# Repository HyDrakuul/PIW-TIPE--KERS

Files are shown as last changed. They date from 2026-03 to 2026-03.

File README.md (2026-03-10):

# TIPE Flywheel Curve Analysis

**Project purpose:**
This personal project is centered around acquiring, processing, and comparing rotational speed curves from a flywheel setup (volant d'inertie). It combines embedded data acquisition (Arduino), serial communication (Python), and data analysis/plotting to evaluate mechanical energy and behavior. The model used for this project was entirely designed and manufactured by me (model available in 3D_model/, designed on Autodesk Fusion 360) and 3D printed with PLA filament.

---

## What’s in this repository

- **Arduino firmware**: `src/tiperoue/tiperoue.ino`
  - Measures rotations via inductive hand made sensors.
  - Sends `tours/s` and timestamp values over Serial.
  - Displays speed on an LCD.

- **Python acquisition scripts**:
  - `src/data_acquisition.py` – reads serial data, plots it, and optionally saves curves to CSV.
  - `src/TIPEcourbe.py` – lightweight acquisition + plotting helper.
  - `src/comparaisons.py` – compares stored curves and computes rotational energy.

- **Tests & hardware validation**:
  - `tests/test_graphical.py` – simple tkinter GUI that stops a long-running loop.
  - `tests/testbobine/testbobine.ino` – test sketch for validating hand-made sensor coils (bobines) via analog voltage readings.

- **Data & output folders**:
  - `raw_datas/` – stored measurement CSVs.
  - `bin_curves/` – generated plot exports (curve images).
  - `docs/` – documentation notes and supplementary materials.
  - `tipe-courbes/` – additional curve-related files.
  - `3D_model/` - 3D model in .step format (for maximum compatibility) and in .f3d (origin format, Fusion 360 compatible).

---

##  Skills developed

This project demonstrates and helps develop the following skills:

- Serial communication and realtime data acquisition (Arduino ↔ Python)
- Signal processing and data cleaning (conversion from raw serial strings)
- Data visualization (matplotlib plots of speed and energy curves)
- Reproducible data structuring with CSV exports
- Basic GUI interaction (user validation of measurement runs)
- Embedded firmware development (interrupts + timing in Arduino)
- 3D printing, 3D modelling, electromagnetic and mechanical physics.

---

##  Running the project

### 1) Upload the Arduino sketch

1. Open `src/tiperoue/tiperoue.ino` in the Arduino IDE.
2. Connect your Arduino and select the correct board/port.
3. Upload the sketch.

### 2) Acquire data with Python

1. Install Python dependencies: `pyserial`, `matplotlib`, `numpy`.
2. Run the acquisition script:

```bash
python src/data_acquisition.py
```
4. Run the experiment while running the two programs in parallel. 
3. A plot will appear at the end of the experiment. If you confirm the curve looks valid, it will be appended to a CSV.

---

##  How to reproduce / customize the data storage 

### Change where curves are stored

The storage locations are explicitly written in `src/data_acquisition.py` for the CSV file and experiment counter file. To make this reproducible:

- Modify the paths near the bottom of `src/data_acquisition.py` to target a relative folder (e.g., `./raw_datas/`) instead of an absolute desktop path.
- Example: replace `"/Users/…/TIPE/TIPE_experience2.csv"` with `"raw_datas/TIPE_experience2.csv"`.

### Load curves from files instead of hardcoded arrays

In `src/comparaisons.py`, curve data is currently embedded as multi-line strings (`rw_temps`, `rw_vitesse`, ...). To reproduce the analysis with your own curves:

1. Save data into a CSV (as above).
2. Replace the hardcoded strings with a loader such as `numpy.loadtxt` or `pandas.read_csv`.

---

##  Project structure (detailed)

This project is organized into a few main folders. The following breakdown
explains the purpose of each folder and the key files you’ll likely work with.

### Core source code (`src/`)

- `src/tiperoue/` – **Arduino firmware**
  - `tiperoue.ino` : main sketch that reads the sensor coils, computes rotational
    speed, prints it over Serial, and displays it on an LCD.

- `src/data_acquisition.py` – **serial data acquisition and CSV export**
  - Connects to the Arduino over a serial port.
  - Collects and cleans the raw velocity/timestamp stream.
  - Optionally saves each measurement run as a CSV.

- `src/TIPEcourbe.py` – **simple acquisition + plotting helper**
  - Smaller script for quickly plotting a single run without saving.

- `src/comparaisons.py` – **curve comparison + energy plotting**
  - Loads previously recorded curve data (currently embedded in the script)
  - Plots multiple flywheel curves together and computes rotational energy.

### Test & validation (`tests/`)

- `tests/test_graphical.py` – GUI loop-stop demo
  - Useful to verify that you can interrupt a long-running acquisition cleanly.

- `tests/testbobine/` – sensor coil validation
  - `testbobine.ino` : Arduino sketch that reads an analog pin (A0) and prints
    the voltage. This is intended to validate hand-made sensor coils / wiring.

### Data, exports and documentation

- `raw_datas/` – stored measurement CSV files (raw acquisitions).
- `bin_curves/` – exported plot images (curve screenshots, etc.).
- `docs/` – additional documentation notes, plan of the model, results presentations and bibliography.
- `tipe-courbes/` – additional curve assets (e.g., scripts or export formats).

### 3D model (`3D_model`)

- Includes two files who contain the 3D model of the modulable KERS system (same model just differents extensions). 

---

##  Notes

- For best reproducibility, keep all generated data inside `raw_datas/` and update the path constants in the Python scripts.
- If you want to run analyses on new data sets, update `src/comparaisons.py` to load from the relevant file(s) rather than using embedded arrays.

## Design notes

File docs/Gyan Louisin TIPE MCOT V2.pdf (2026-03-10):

39070 Gyan Louisin

### Modélisation et Étude d’un système mécanique de récupération d’énergie cinétique

Le 29 juillet 2009, lors du Grand Prix de Hongrie, le pilote Lewis Hamilton réalise une sortie exceptionnelle du peloton grâce à une utilisation maitrisée d’un tout nouveau système mécanique adopté pour la première fois dans l’histoire de la F1: le Système de Récupération d’Énergie Cinétique, ou SREC. L’introduction de ce système dans le sport automobile a ouvert de nouvelles perspectives en terme de stratégie de course. Il me paraissait donc intéressant d’étudier le fonctionnement de ce système et comment il pouvait impacter les performances d’un véhicule.

Positionnement thématique (ETAPE 1)

PHYSIQUE (Mécanique),INFORMATIQUE (Informatique pratique),SCIENCES INDUSTRIELLES (Conception de produit)
Mots-clés (ETAPE 1)
Mots-Clés (en français) | Mots-Clés (en anglais)
Système de Récupération d’Énergie Cinétique | Kinetic Energy Recovery System
Volant d’inertie | Flywheel
Moment d’inertie | Moment of Inertia
Modélisation 3D | 3D Modeling
Informatique Pratique | Practical Computing

Bibliographie commentée

Introduit dans la compétition de Formule 1 depuis 2009 [1], le SREC est un système basé sur la conversion énergétique. En effet, une course est une succession d'accélération et de décélérations et l’énergie cinétique fournie par le moteur, convertie en chaleur lors des phases de décélération, est perdue. L’idée du SREC est donc de stocker cette énergie cinétique avant qu’elle ne soit dissipée sous forme de chaleur en la convertissant en un autre type d’énergie (énergie électrique, de rotation...) pour ensuite être réutilisée ultérieurement, fournissant un gain de puissance, certes temporaire, mais non négligeable dans une course.

Ainsi, il existe principalement quatre types de SREC [2] : électrique, mécanique, hydraulique et hydroélectrique. Chacun de ces systèmes repose sur une méthode différente de stockage de l’énergie cinétique fournie par le moteur.

J’ai alors cherché à comprendre comment de tels systèmes pouvaient être dimensionnés afin d’être véritablement efficaces. Une étude approfondie de chacun des systèmes était alors nécessaire. J’ai exclu de mon étude les SREC hydraulique et hydroélectrique, de par leur complexité trop importante en vue d’une modélisation ultérieure.

Avant comparaison, il est nécessaire de préciser le fonctionnement de ces systèmes. Ainsi, les SREC électrique utilisent soit des batteries chimiques (Li-ions), soit des supercondensateurs pour le stockage de l’énergie électrique [2]. Les SREC mécanique utilisent des volants d’inertie, masses tournantes qui, comme leur nom l’indique, permettent le stockage par inertie d’une énergie cinétique de rotation, donnée par
avec J le moment d’inertie du volant en | , ω sa vitesse de rotation en | [4].

Après une première lecture des études comparatives réalisées en [2] et [3], on a pu exclure les SREC électrique utilisant des batteries, car malgré leurs avantages en termes de coût et de capacité de stockage, elles possèdent une densité de puissance très faible comparée au deux autres ([3]: « Tableau V.2 »; environ 300 W/kg contre plusieurs kW/kg), traduisant sa difficulté à transmettre une puissance importante au véhicule, ce qui oblige l’utilisation de batteries très onéreuses. Cela nous permet alors de nous concentrer sur les SREC mécanique et à supercondensateurs.

E = 1
2 ⋅ J ⋅ ω² | kg . m² | m .s⁻¹

39070 Gyan Louisin
Ensuite, [2] nous présente le SREC mécanique comme étant le plus intéressant selon des critères comme le coût et le rendement global. Cependant, il est aussi expliqué que cette étude a été faites à une époque où l’utilisation des supercondensateurs dans les SREC n’était pas industrielle et encore trop onéreuse.

SREC électriques mis de coté, j’ai étudié plus en profondeur les SREC mécanique. Ainsi, ces systèmes sont composés d’un couplage moteur-volant et d’un couplage volant-roue [1], mais l’aspect le plus important pour un SREC réside dans le dimensionnement du volant [4].

L’étude de [4] a permis de mettre en évidence l’influence de la forme du volant (cylindre plein, creux, « iso-contraintes »…) sur l’efficacité du système. En effet, cela provient directement de l’expression du moment
d’inertie, prenant en compte la répartition de la masse dans le volant: | avec mj une masse

individuelle du volant en kg et rj la position radiale de la masse mj en m. Dans cette optique, la masse du volant doit être relativement élevée et répartie le plus possibles sur sa périphérie afin de maximiser l’énergie stockée.

Problématique retenue

Comment réutiliser l’énergie cinétique emmagasinée par un SREC mécanique afin d’augmenter les performances d’un véhicule lors d’une course ?

Objectifs du TIPE

-Modéliser un SREC modulable, permettant d’effectuer diverses expériences pouvant mettre en évidence l’importance d’un tel système lors d’une course automobile.

-Réaliser la mesure de la vitesse de rotation de différents types de volants au cours du temps, permettant de mettre en relief l’importance de la masse et de sa répartition sur les performances du système.

-Montrer comment il est possible de transmettre l’énergie stockée du volant à la roue en modélisant un système de transmission roue-volant (embrayage).

-Mesurer le rendement du système ainsi fabriqué et mettre en lumière ses défauts par rapport à un système réel.

Références Bibliographiques (Étape 1)

[1] Alberto Boretti, Kinetic Energy Recovery System for Racing Cars, édité par SAE International, ISBN-13: 9780768079944
[2]Radhika Kapoor, C. Mallika Parveen, Member, IAENG, Proceedings of the World Congress on Engineering 2013 Vol III, Comparative Study on Various KERS,July 3 - 5, 2013, London, U.K.
[3]Khaled Itani. Récupération d’énergie pour système intégré moteur roue, application au véhicule électrique. Energie électrique. Université Paris Saclay (COmUE), 2017. Français. NNT: 2017SACLN025 . tel-01558984
[4]FAURE, F. Magnetic suspension for flywheel; Suspension magnetique pour volant d'inertie. 2003.TRN: FR0504123
[5]John Nussey, Arduino Pour les Nuls, 3e édition, édité par Pour Les Nuls, ISBN-13: 9782412077351

J = (

∑
j

### m jrj

2)

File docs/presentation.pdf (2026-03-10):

# Modélisation et

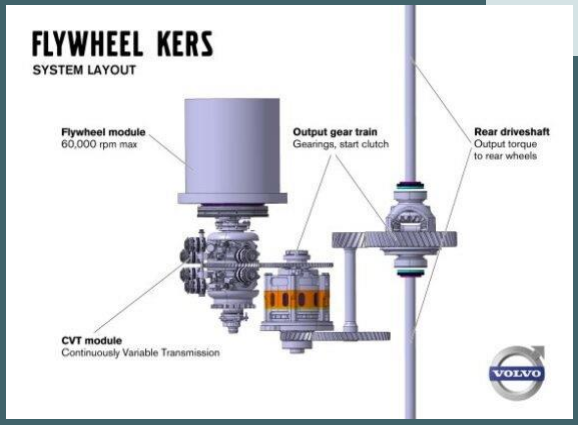
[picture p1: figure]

# Étude d’un système mécanique de récupération d’énergie

cinétique.

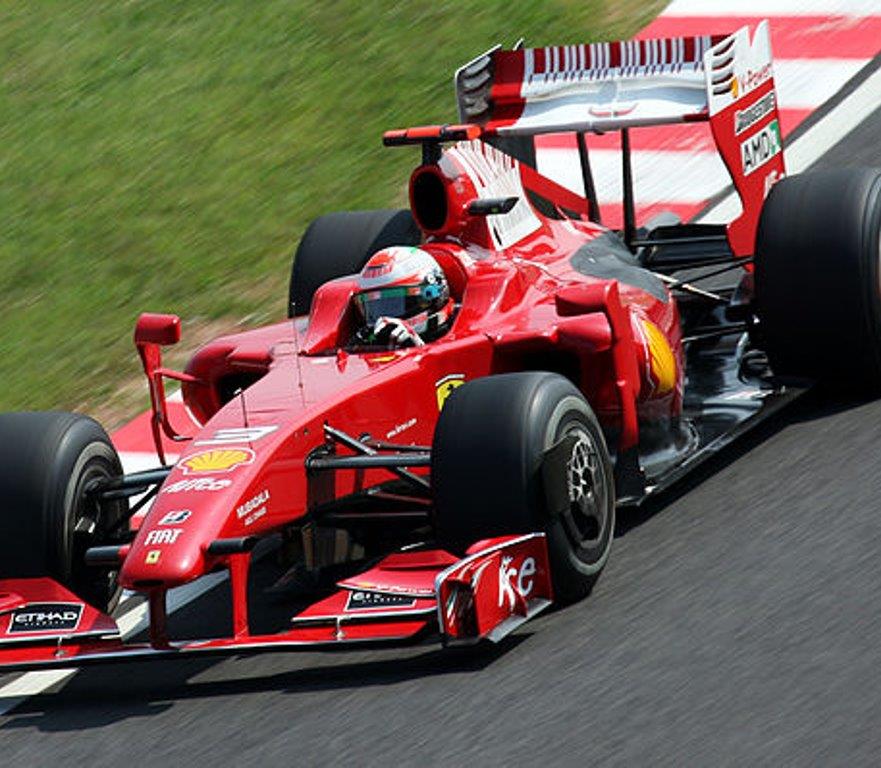
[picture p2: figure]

N°39070 Gyan Louisin

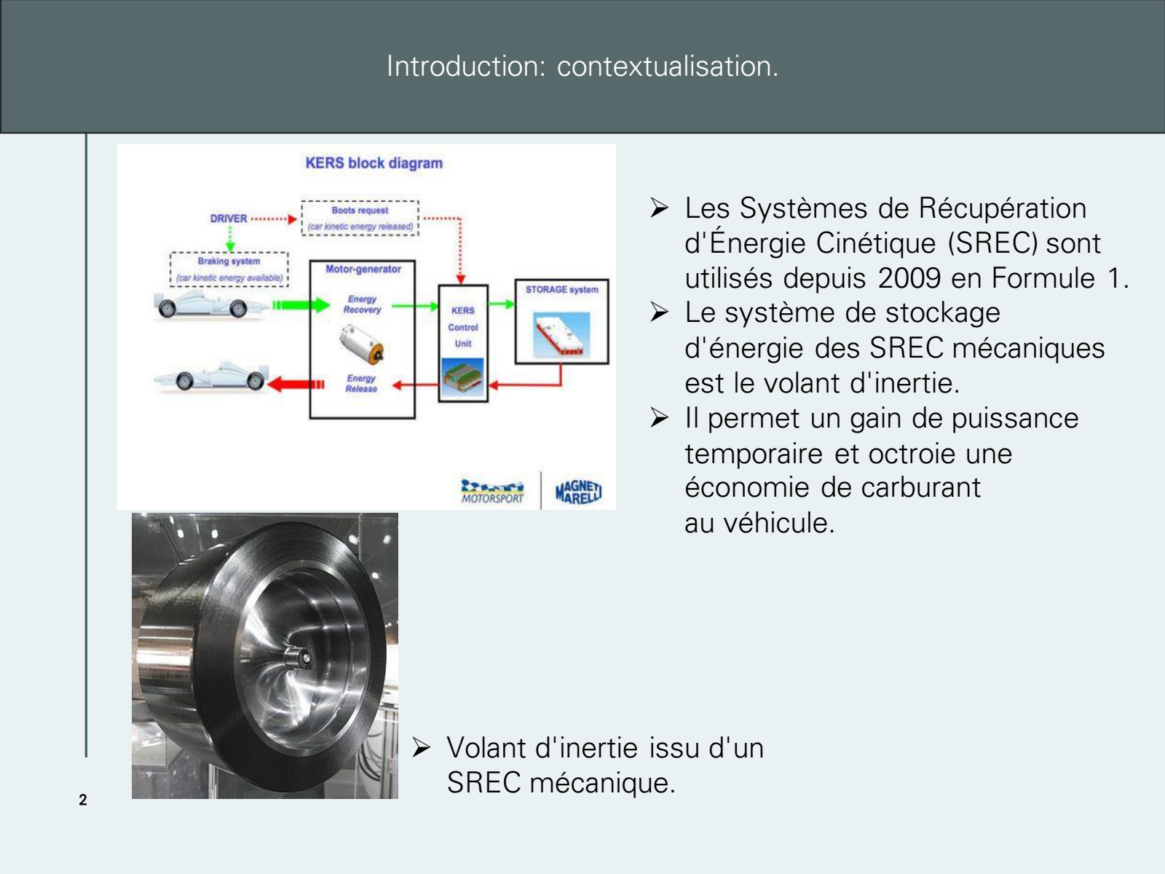
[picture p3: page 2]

2

Introduction: contextualisation.

- Volant d'inertie issu d'un SREC mécanique.
- Les Systèmes de Récupération d'Énergie Cinétique (SREC) sont utilisés depuis 2009 en Formule 1.
- Le système de stockage
d'énergie des SREC mécaniques est le volant d'inertie.
- Il permet un gain de puissance temporaire et octroie une
économie de carburant
au véhicule.

ΓΔ

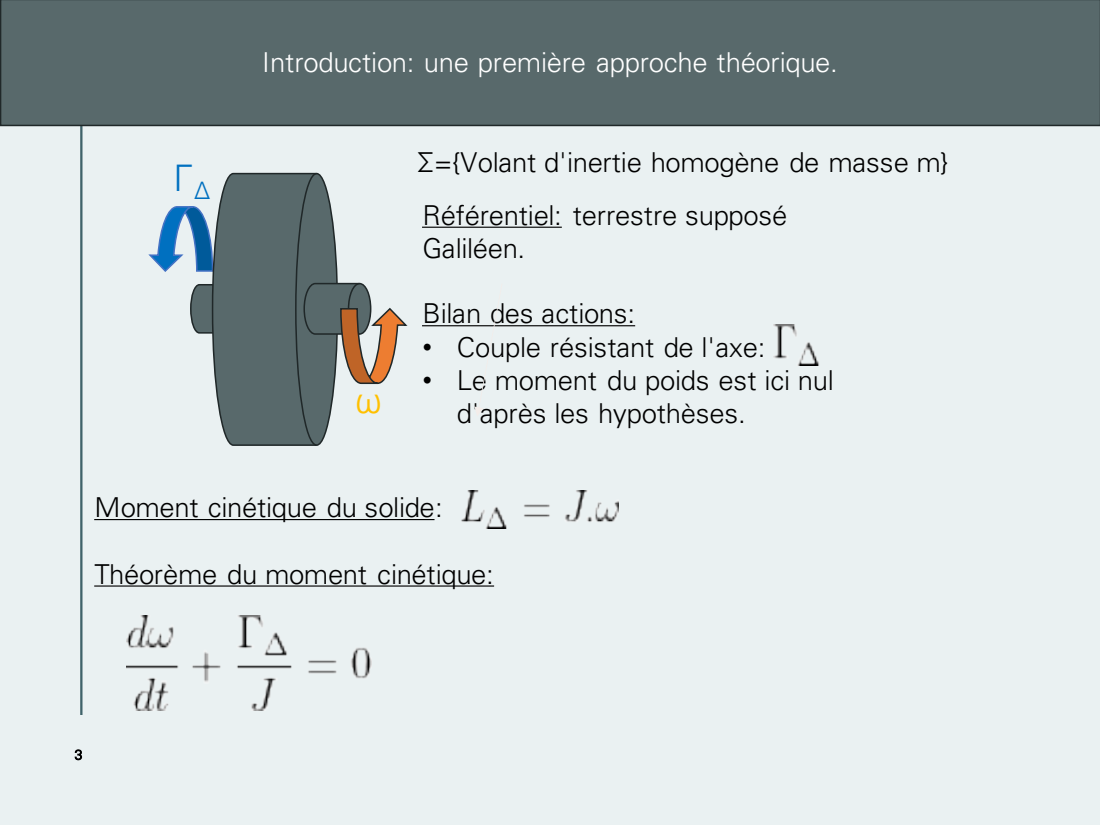
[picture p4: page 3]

Introduction: une première approche théorique.

Σ={Volant d'inertie homogène de masse m}

Référentiel: terrestre supposé
Galiléen.

Bilan des actions:
• Couple résistant de l'axe:
• Le moment du poids est ici nul

d'après les hypothèses.

Moment cinétique du solide:

Théorème du moment cinétique:

4

Introduction: une première approche théorique.

Une première expression de la vitesse du volant :

L'expression de l'énergie cinétique de rotation stockée:

L'expression du moment d'inertie du volant:

L'énergie stockée par le volant dépend de son moment d'inertie et donc de sa géométrie.

Comment réutiliser l’énergie cinétique emmagasinée par un SREC mécanique afin d’augmenter les performances d’un véhicule lors d’une course ?

5

Plan de la Présentation.

I. Modélisation: la construction du modèle réduit.

II. Expériences et résultats:

A. Expérience n°1: à la recherche d'un volant d'inertie optimal.
B. Expérience n°2: analyse des performances du système optimisé.

III. Bilan et discussion des limites du problème.

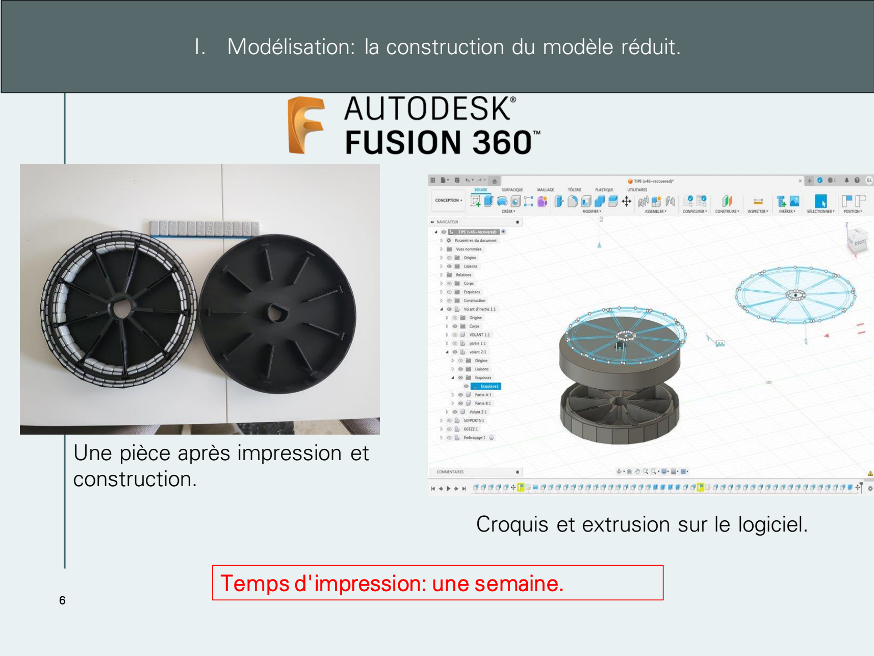
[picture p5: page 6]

6

I. Modélisation: la construction du modèle réduit.

Croquis et extrusion sur le logiciel.

Une pièce après impression et construction.

Temps d'impression: une semaine.

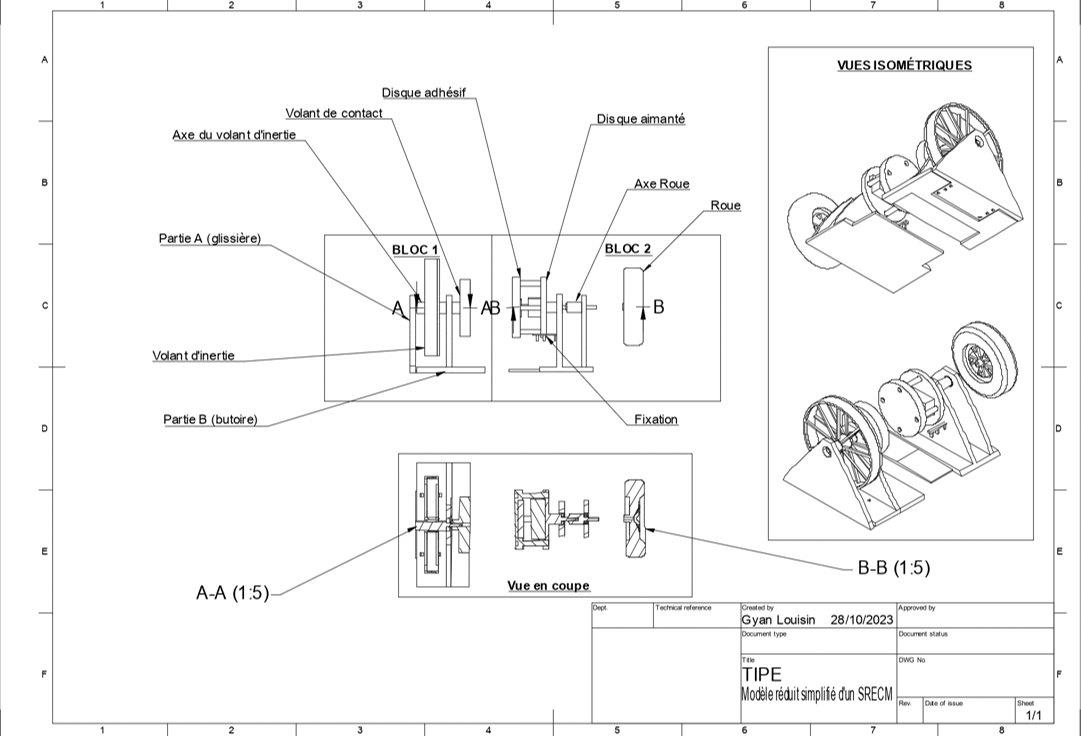
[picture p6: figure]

7

I. Modélisation: la construction du modèle réduit.

L'impression du modèle 3D.

8

I. Modélisation: la construction du modèle réduit.
- Objectif du modèle: simuler le transfert d'énergie du volant en décélération vers la roue.

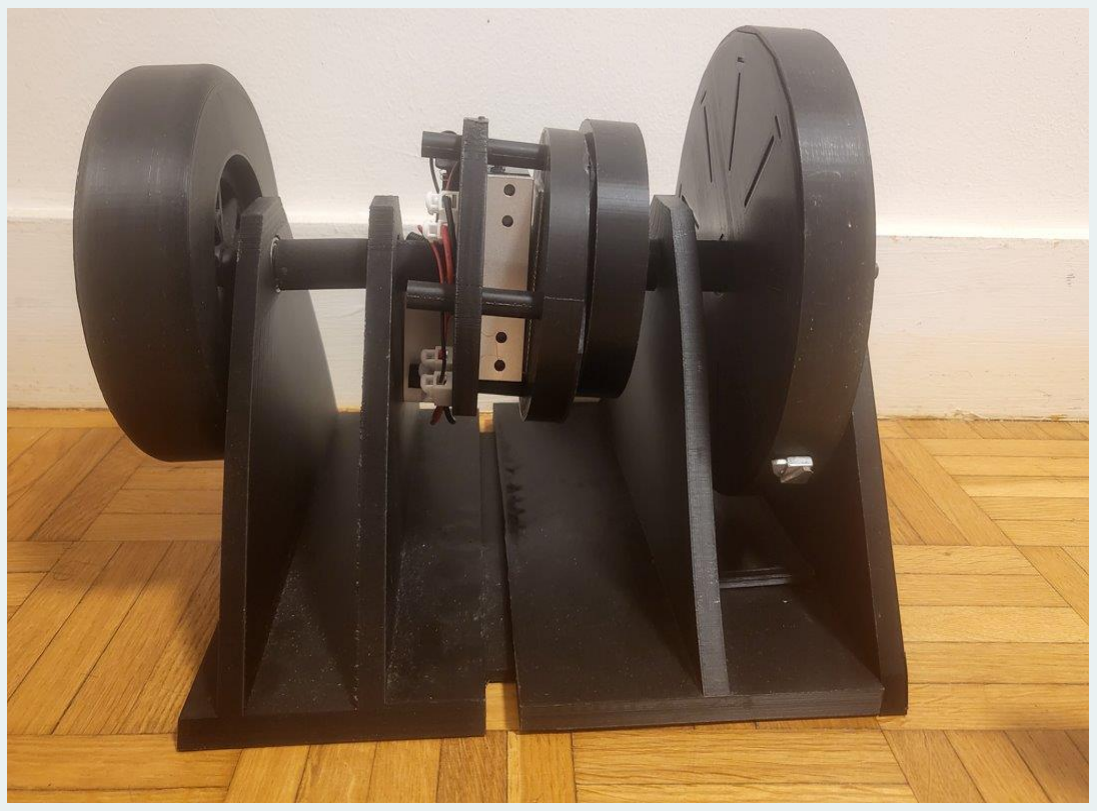
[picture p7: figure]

Comment obtenir la vitesse de rotation des différentes pièces ?

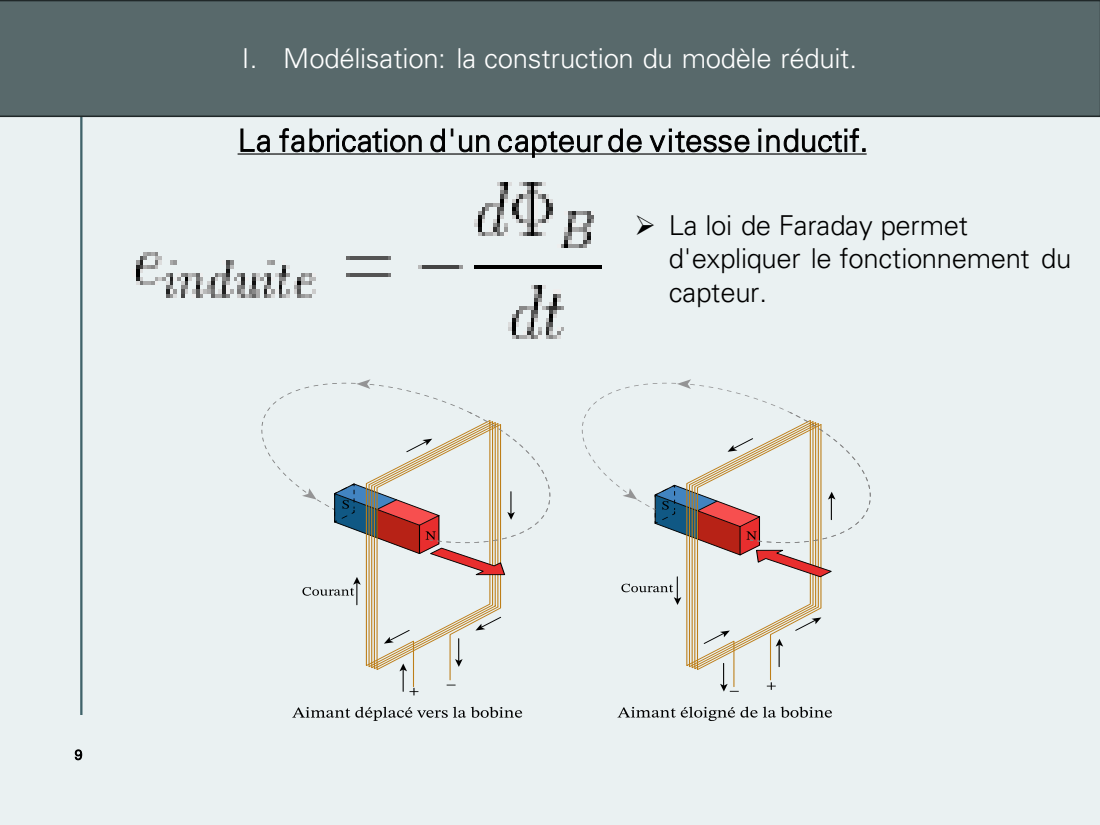
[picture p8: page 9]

I. Modélisation: la construction du modèle réduit.

La fabrication d'un capteur de vitesse inductif.

➢ La loi de Faraday permet
d'expliquer le fonctionnement du
capteur.

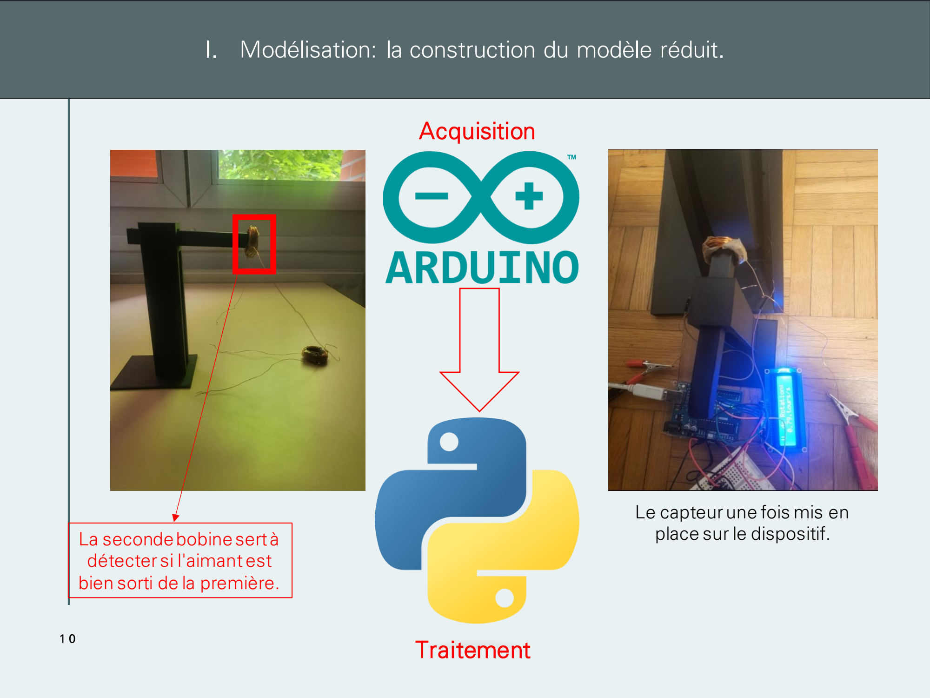
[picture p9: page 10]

10

I. Modélisation: la construction du modèle réduit.

La seconde bobine sert à
détecter si l'aimant est
bien sorti de la première.

Acquisition

Traitement

Le capteur une fois mis en place sur le dispositif.

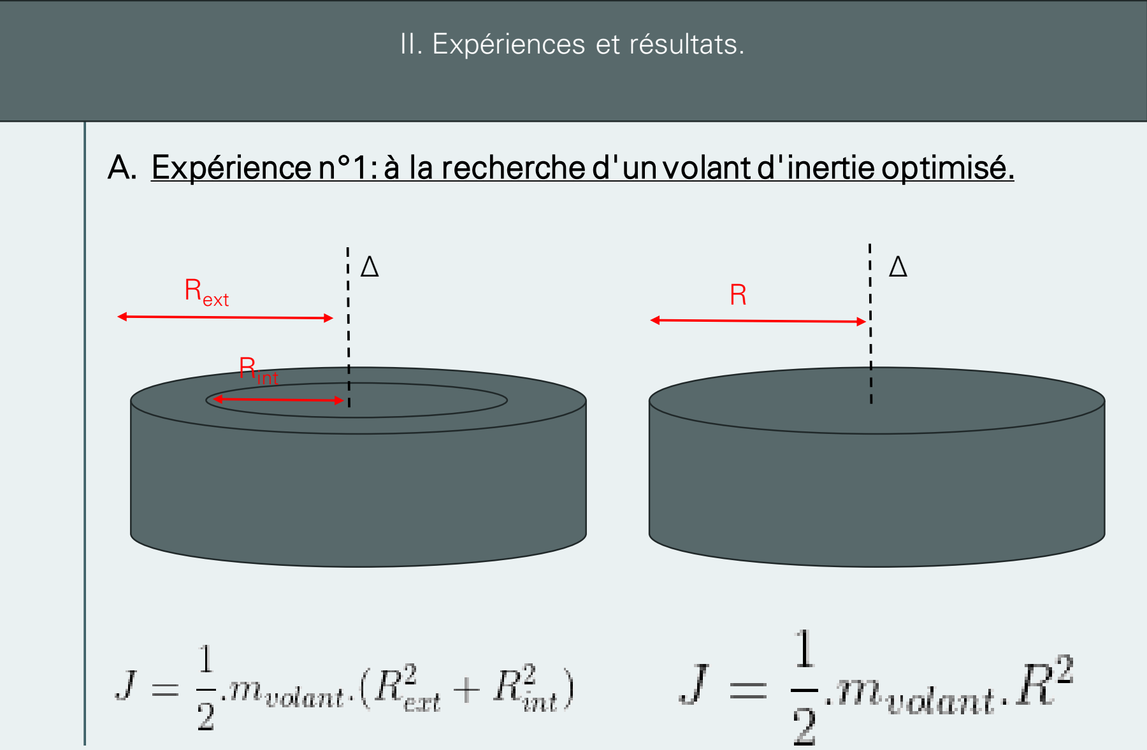
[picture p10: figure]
II. Expériences et résultats.; Rext; Rint

11

A. Expérience n°1: à la recherche d'un volant d'inertie optimisé.

12

Le montage utilisé.

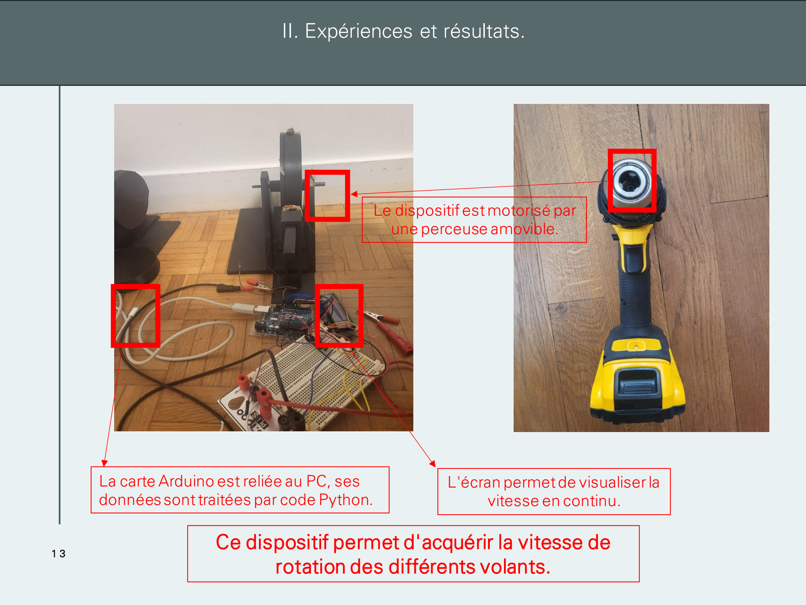
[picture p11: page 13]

13

L'écran permet de visualiser la vitesse en continu.

Le dispositif est motorisé par une perceuse amovible.

La carte Arduino est reliée au PC, ses données sont traitées par code Python.

Ce dispositif permet d'acquérir la vitesse de rotation des différents volants.

| Volant 1 | Volant 2 | Volant 3 | Volant4
Rayon(s) (cm) | Rint= 7.90 Rext= 9.20 | 9.20 | 6.50 | 9.20
Masse (kg) | 1.5 | 2 | 1.1 | 0.5
Répartition de la masse | Sur les bords extérie urs | Uniforme | Autour de l'axe/Uniforme | Vide
Moment d'inertie (kg.m² ) | (6.6±0.1)*10⁻² | (8.5±0.1) *10⁻³ | (2.32±0.04)*10⁻³ | (2.53±0.03)*10⁻³

14

Tableau présentant les caractéristiques des volants étudiés.

- Incertitude type sur le rayon: 0.06 cm

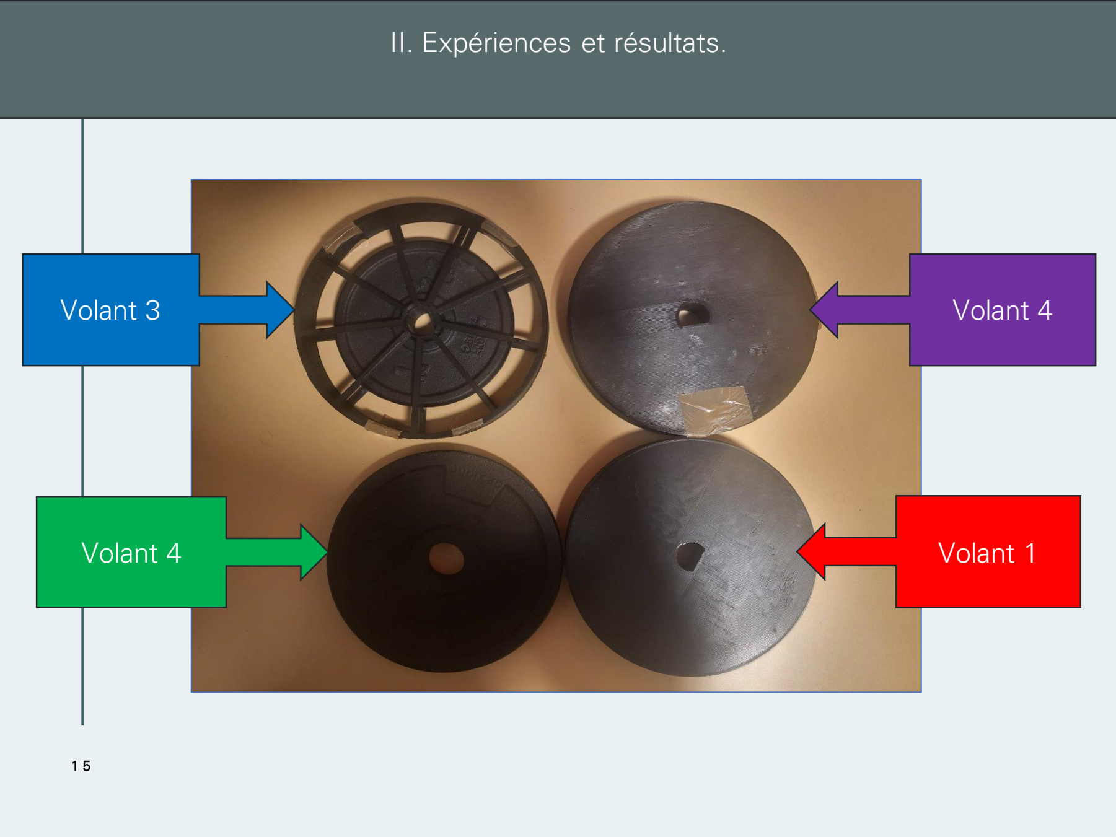
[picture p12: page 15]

15

Volant 1

Volant 3 | Volant 4

Volant 4

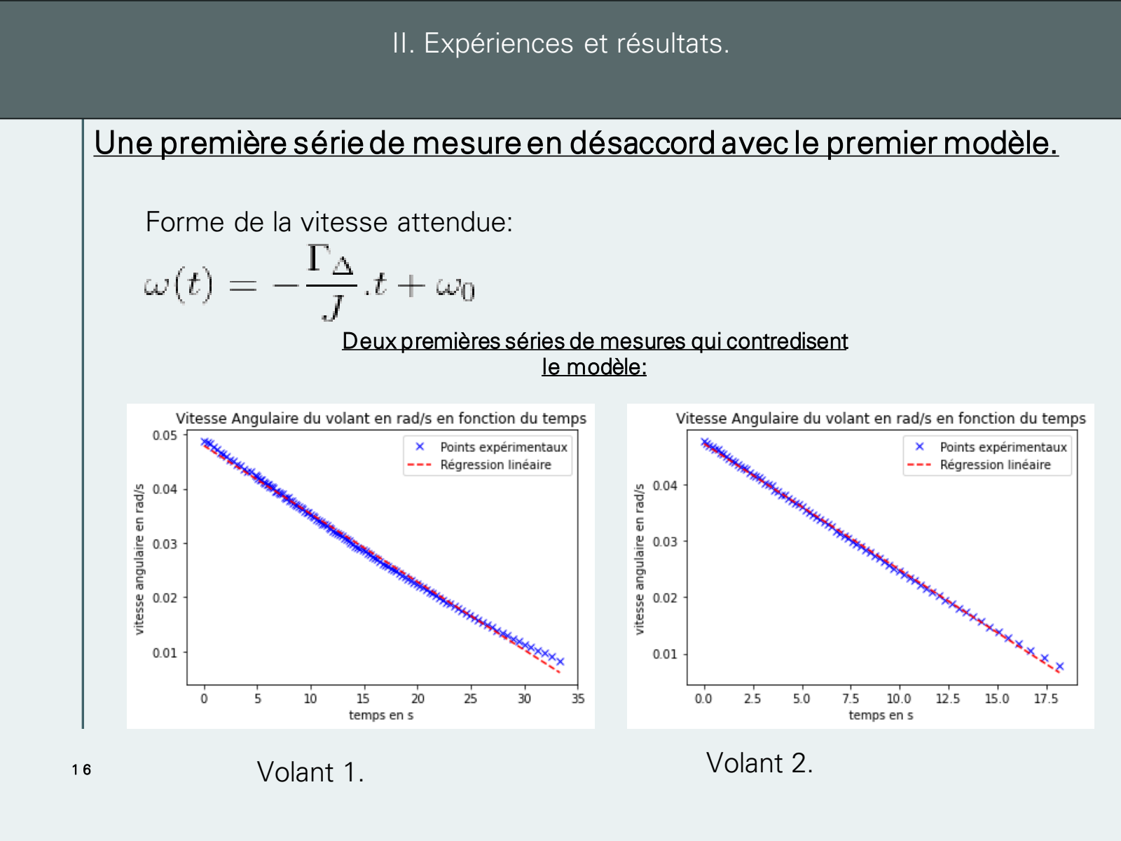
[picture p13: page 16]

16

Une première série de mesure en désaccord avec le premier modèle.

Forme de la vitesse attendue:

Deux premières séries de mesures qui contredisent le modèle:

Volant 1. | Volant 2.

17

Courbe présentant la phase de freinage (gain de vitesse du volant) et la phase de décélération, qui semble présenter une tendance non-linéaire.

18

Corrections apportées pour observer plus de points:
- Repositionnement du capteur.
- Minimisation des frottements parasites au niveau des roulements.
- Limitation des ballotements du volant.

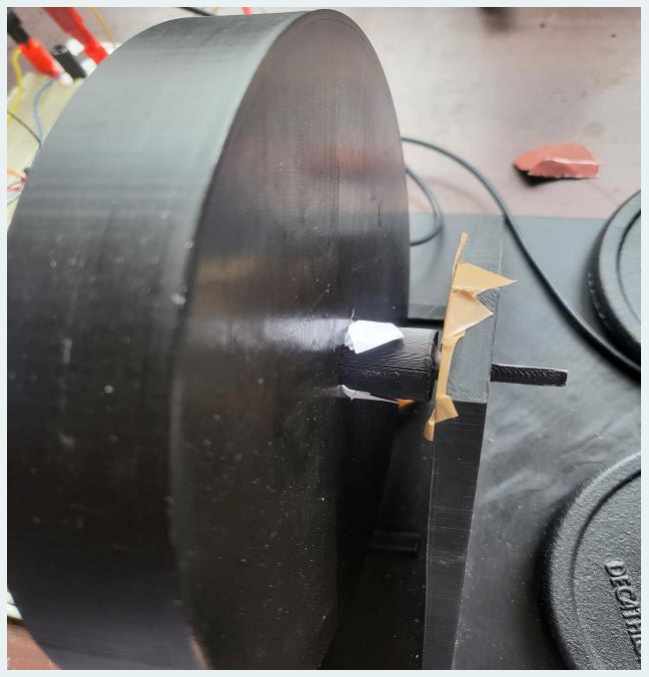
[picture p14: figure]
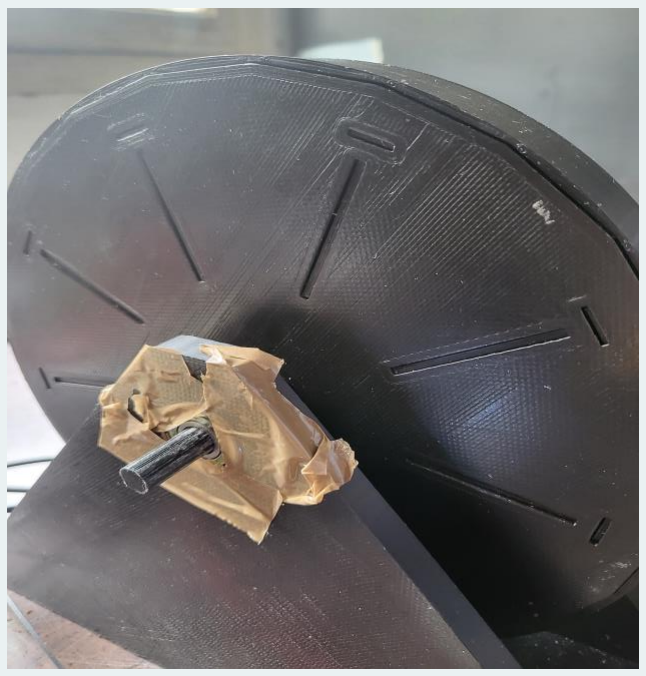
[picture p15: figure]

19

Comparaison des courbes obtenues avant et après correction pour un même volant:

On observe une nette amélioration des performances du système.

20

La correction du modèle théorique.

Ajout d'un couple de frottements visqueux de la forme:

Le TMC donne:

Une expression plus plausible de la vitesse:

- Le temps caractéristique dépend directement du moment d'inertie.

21

Une première comparaison pour une vitesse initiale équivalente.

Les résultats.

22

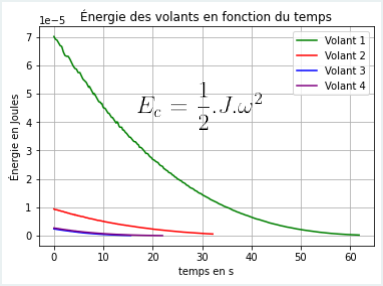
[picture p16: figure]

Le premier volant présente sans surprise la meilleure performance.

23

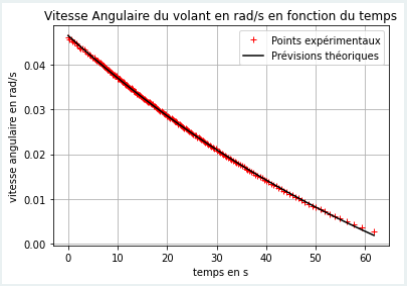
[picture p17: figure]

0 si ω<0

Si ω>0

- Le modèle théorique
parait ici cohérent avec
l'expérience.
- La modélisation via le module curve_fit permet d'accéder au temps caractéristique et aux autres données du problème.

Résumé de cette première expérience.; Terme pré-exponentiel.; Terme constant.; Temps caractéristique.; Valeurs numériques obtenues après une série de 10 mesures indépendantes:
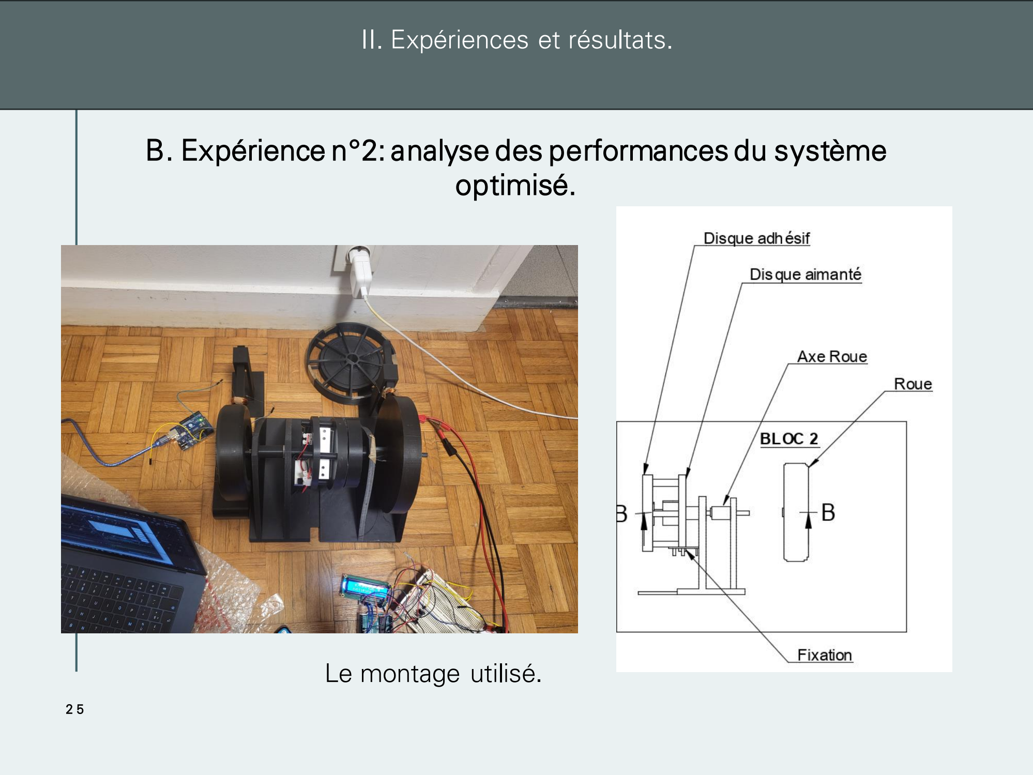
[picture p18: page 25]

25

B. Expérience n°2: analyse des performances du système optimisé.

Le montage utilisé.

26

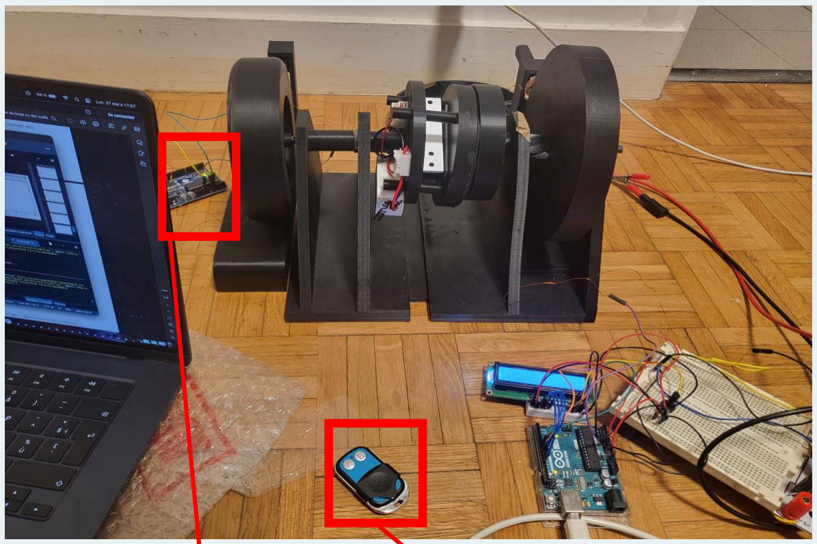
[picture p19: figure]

Une deuxième carte arduino a été ajoutée.

L'embrayage est activé à distance à l'aide d'un interrupteur à distance.

Ce montage permet de simuler l'activation du SREC lors d'une course.

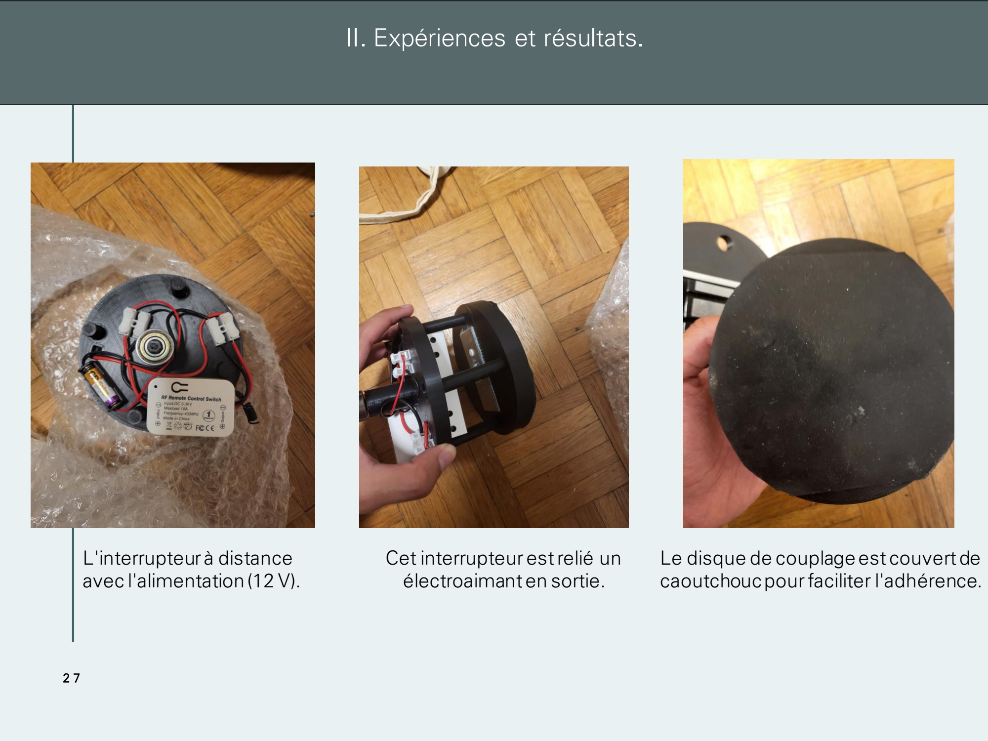
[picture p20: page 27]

27

Le disque de couplage est couvert de caoutchouc pour faciliter l'adhérence.

Cet interrupteur est relié un électroaimant en sortie.

L'interrupteur à distance
avec l'alimentation (12 V).

28

Les résultats.

On observe la phase de couplage, qui mène à une forte perte de vitesse du volant, qui se stabilise par la suite.

29

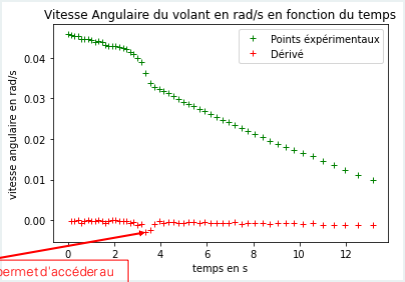
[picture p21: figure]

Le tracé de la dérivé permet d'accéder au temps où le couplage a lieu dans un soucis de synchronisation temporelle des cartes arduino.

La valeur minimale permet d'accéder au temps de couplage rapidement.

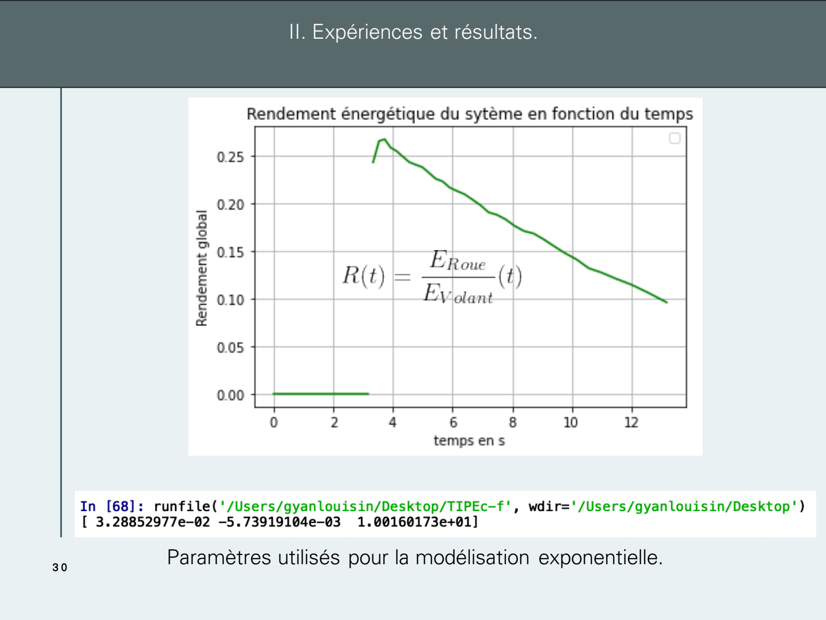
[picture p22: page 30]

30

Paramètres utilisés pour la modélisation exponentielle.

31

Phase de
couplage.

Durant la phase de couplage, la roue est accélerée et donc gagne de l'énergie.

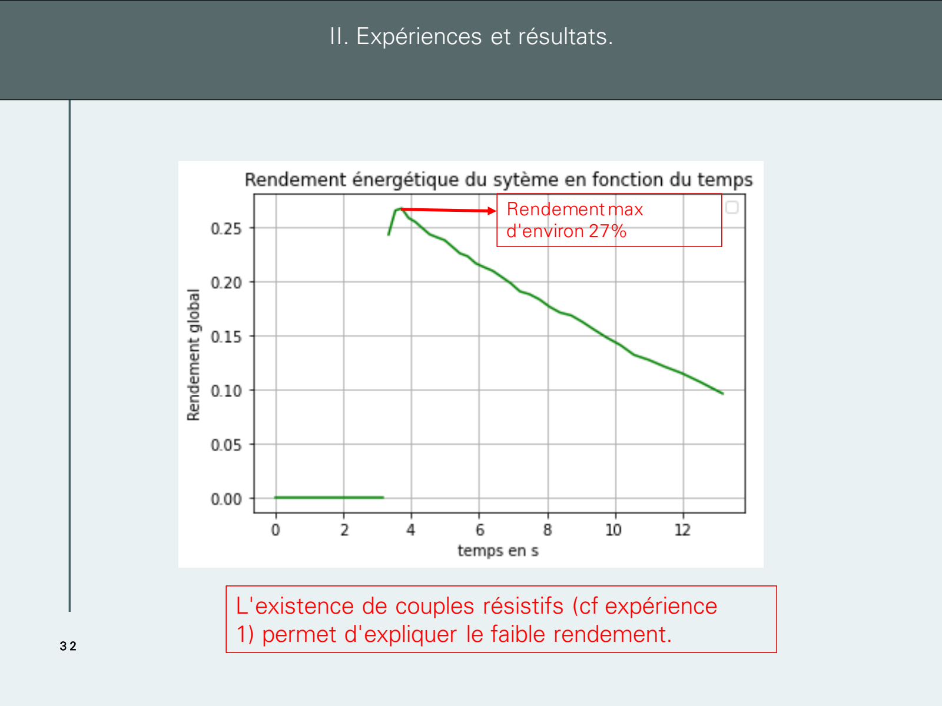
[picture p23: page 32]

32

Rendement max
d'environ 27%

L'existence de couples résistifs (cf expérience
1) permet d'expliquer le faible rendement.

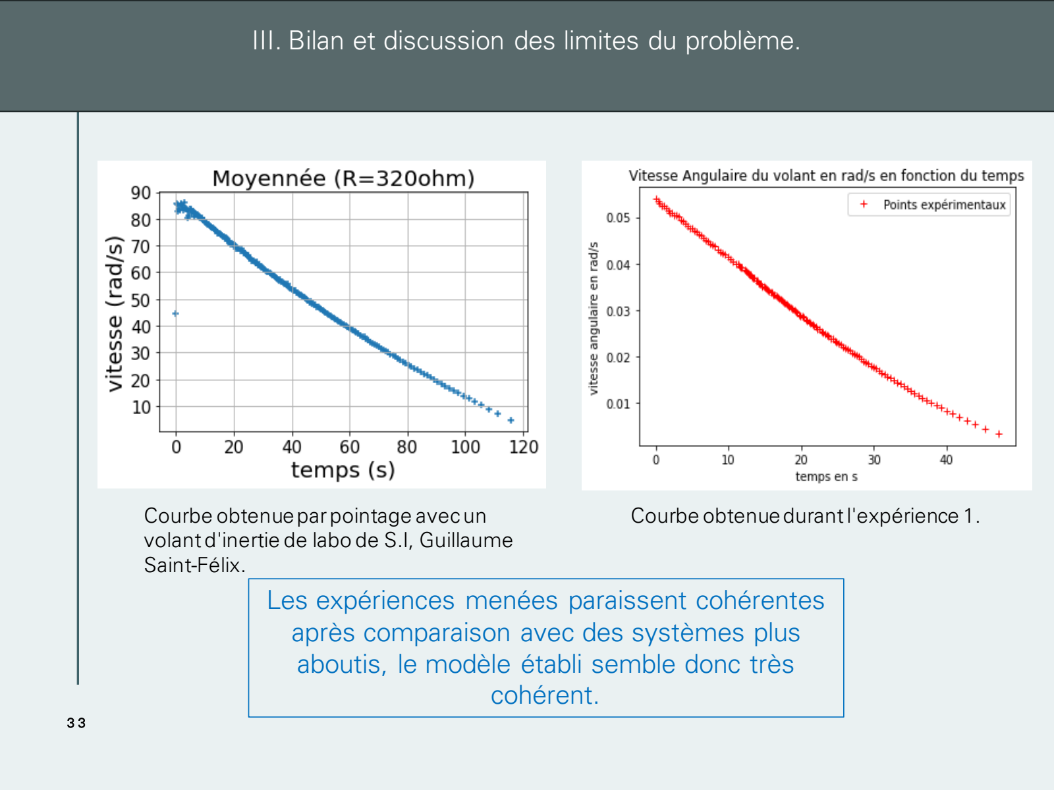
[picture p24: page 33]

33

III. Bilan et discussion des limites du problème.

Les expériences menées paraissent cohérentes après comparaison avec des systèmes plus aboutis, le modèle établi semble donc très cohérent.

Courbe obtenue par pointage avec un volant d'inertie de labo de S.I, Guillaume Saint-Félix.

Courbe obtenue durant l'expérience 1.

34

III. Bilan et discussion des limites du problème.

Principales limites relevées:
- Des frottements d'axe et de roulements trop importants.
- Une vitesse de rotation trop faible.
- Un matériau peu adapté (PLA).

Merci de votre attention.

35

36

Annexes.

Démonstration de l'expression du volant d'inertie pour un cylindre creux de hauteur h:

Masse du volant.

37

Annexes.

Origines des images externes:
- Diapo 1:
- Schéma industriel de SREC: https://www.cnetfrance.fr/cartech/volvo-kers-hybride-39761146.htm#item=3 (https://www.cnetfrance.fr/cartech/volvo-kers-hybride-39761146.htm)
- Ferrari F-60 de 2009: https://www.bienpublic.com/magazine-automobile/2022/06/21/le-kers-invente-pour-la-formule-1-depuis-dans-vos-voitures-mais-c-est-quoi (https://www.bienpublic.com/magazine-automobile/2022/06/21/le-kers-invente-pour-la-formule-1-depuis-dans-vos-voitures-mais-c-est-quoi)
- Diapo 2:
- Volant d'inertie industriel: https://fr.wikipedia.org/wiki/Système_de_récupération_de_l%27énergie_cinétique (https://fr.wikipedia.org/wiki/Système_de_récupération_de_l%27énergie_cinétique)
- Schéma explicatif sur
l'induction:https://www.nagwa.com/fr/explainers/527178564976/
- Diapo 34:
- Schéma du module Volant d'inertie d'un
SREC: https://www.cnetfrance.fr/cartech/volvo-kers-hybride-39761146.htm#item=3 (https://www.cnetfrance.fr/cartech/volvo-kers-hybride-39761146.htm)

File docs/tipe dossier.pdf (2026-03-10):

1) Programme Arduino des capteurs de vitesse.

#include <LiquidCrystal.h> //definition de pi; //initialisation des ports const int pinBobineVitesse=A0; const int pinBobineDetection=A1; //paramétrage de l'écran LiquidCrystal lcd(7, 8, 9, 10, 11, 12);; volatile unsigned long debut =0; volatile unsigned long fin=0; //defintion d'une variable drapeau volatile bool flag=false; void setup() { // inilitialisation de l'écran lcd.begin(16, 2); lcd.print("V. de Rotation:"); //Ports de bobine en INPUT pinMode(pinBobineVitesse,INPUT); pinMode(pinBobineDetection,INPUT);; boucle pinMode(2,OUTPUT); Serial.begin(9600);; HIGH; Serial.println("Ready"); }

#define PI 3.1415926535897932384626433832795

// definition des variables de debut et de fin de tour

//defintion d'un port quelconque qui servira de condition de sortie de la

//definition d'une interruption logique (on active la fonction detectionAimant): on interrompt la boucle si le port 2 passe d'un niveau LOW à

attachInterrupt(digitalPinToInterrupt(2),detectionAimant,RISING);

void loop() {
// si une tension est detectée par la première bobine, on sort de la boucle pour entrer dans la fonction detection aimant (passage de LOW à HIGH)
if (analogRead(pinBobineVitesse) != 0){
digitalWrite(2,HIGH);
}
//si le drapeau est levé, on considère que l'aimant a fait un tour (il est dejà passé une fois)
if (flag==true){
fin=micros();
//calcul de la vitesse à l'aide des variables mises à jour float vitesse=(2*PI*74.96)/((fin-debut)*pow(10,-3));
// impression des données dans le buffer Serial.print(vitesse);Serial.print(" tours/s ; ");Serial.print(fin*pow(10,-6));Serial.println(" secondes"); // mise à jour de l'écran
lcd.setCursor(2, 1);
lcd.print(vitesse);
lcd.setCursor(7, 1);
lcd.print("tours/s");
// on baisse le drapeau et on réinitialise les variables à la fin du tour flag=false;
fin=0;
debut=0;

}

}

void detectionAimant(){

demarre le compteur if (debut == 0){ debut=micros();; d'éviter les erreurs de mesures; delayMicroseconds(1); }; flag=false;; continuer la boucle principale else{

// si l'aimant n'est pas déjà passé devant la bobine avant detection, on

//tant que l'aimant ne passe pas devant la 2nde bobine, on attend afin

while (analogRead(pinBobineDetection)==0){

//le drapeau reste baissé car l'aimant commence son tour

// si l'aimant passe pour la 2nde fois, on lève le drapeau, ce qui permet de

flag=true;
}
digitalWrite(2,LOW);
}
2) Code Python: La collecte des données.

#!/usr/bin/env python3

# -*- coding: utf-8 -*-

"""
Created on Thu Feb 22 12:34:29 2024

@author: gyanlouisin
"""

import numpy as np
import select
import serial
import matplotlib.pyplot as plt
import csv
import tkinter as tk

#définition du port de collecte des données (celui où la carte est branchée) ser=serial.Serial('/dev/cu.usbmodem101')

#définition de deux tableaux pour stocker les données traitées vitesseAngulaire=np.array([])

temps=np.array([])
#définition d'un temps d'attente maximum des données tmpsmax=5

#la boucle while permet de récupérer en continue les données

while True:
#cette commande renvoie une liste de données à chaque itération, quand il n'y a plus de données après tmpsmax, elle renvoie une liste vide lecture,_,_=select.select([ser],[],[],tmpsmax)

#si la liste est vide, alors le flux de données c'est arreté, on peut quitter la boucle

if lecture==[]:
break
#si la carte transmet des données, on les traitent avant de les stocker else:

#premier traitement des données brutes, on lit les données puis on les stockent dans une liste

Data=ser.readline().strip().split()
#Différents cas servant à corriger certains bugs

if Data[0]== b'Ready':

continue elif Data[0]== b'ours/s': continue elif Data[1]==b't': break else:; float(Data[0].decode())/93.465); de données; if float(Data[0].decode()) <= 0.50: break

#on remplit les listes au fur et à mesure des itérations vitesseAngulaire=np.append(vitesseAngulaire,

temps=np.append(temps, float(Data[3].decode()))
#après plusieurs expériences, on s'est rendu compte d'un bug pour des vitesses de rotation faibles, cette ligne permet de s'assurer une collecte

table=[temps ,vitesseAngulaire]
print(len(table[1]),len(table[0] ))
table[1] = np.delete(table[1], 0, axis=0) # Supprime le premier élément de vitesseAngulaire
table[0] = np.delete(table[0], 0, axis=0) # Supprime le premier élément de temps
# défintiion d'un temps de réference pour commencer l'echeclle de temps à 0 tempsref=table[0][0]

table=[table[0],table[1]]
#Traçé des courbes pour observer si il n'y a pas de grosses erreurs de mesure x=table[0]

y=table[1]
print(len(x),len(y))
plt.plot(x,y,marker='+',color="blue",linestyle= "None", label="Points expérimentaux")
plt.xlabel("temps en s")
plt.ylabel("vitesse angulaire en rad/s")
plt.title("Vitesse Angulaire du volant en rad/s en fonction du temps") plt.legend()

plt.show()
#Utilisation d'un interface graphique pour valider ou non la série de mesure prise

root=tk.Tk()
Question=tk.messagebox.askquestion("Conservation de la Courbe", "Conserver les données ?", icon="warning")
#Si les résultats sont convenables, on les enregistres dans un fichier .csv

if Question=="yes":

#Permet de numéroter les série de mesures en écrivant une variable numérique comptant le nombre d'essais

with open("/Users/gyanlouisin/Desktop/TIPE/Experience n°.txt", 'r')as g: old_i= g.readlines()
index=int(old_i[0])+1

with open("/Users/gyanlouisin/Desktop/TIPE/Experience n°.txt", 'w') as g: for line in old_i:
if line.strip('\n') !=str(index): g.write(str(index))

colonnes=[index,table[0],table[1]]

with open('/Users/gyanlouisin/Desktop/TIPE/TIPE_experience2.csv', 'a', newline='') as f:
writer=csv.writer(f)
writer.writerow(colonnes)

else:
root.destroy()

root.mainloop()

### La fonction permettant la régression linéaire:

from scipy.stats import linregress as lr

def courbe(table):
x=traitement(table)[0]
y=traitement(table)[1]
print(len(x),len(y))
Regression=lr(x,y) #renvoie une liste contenant les deux paramètres a=Regression[0]
b=Regression[1]
plt.plot(x,y,marker='x',color="blue",linestyle= "None", label="Points expérimentaux")
plt.plot(x, a*x+b, color="red",linestyle="--", label="Régression linéaire plt.xlabel("temps en s")
plt.ylabel("vitesse angulaire en rad/s")
plt.title("Vitesse Angulaire du volant en rad/s en fonction du temps") plt.legend()
print("a= ", a)
print("b= ", b)
return plt.show()

### 3) Curve_fit et Résultats de la première expérience:

import numpy as np
import matplotlib.pyplot as plt
from scipy.optimize import curve_fit
J=6.6e-2 #kg.m-2
#%% temps

rw_temps="""[ 3.34 3.54 3.73 3.93 4.13 4.34 4.55 4.77 4.99 5.21 5.44 5.67
5.91 6.16 6.41 6.67 6.94 7.21 7.49 7.78 8.08 8.39 8.72 9.05
9.41 9.77 10.16 10.57 11. 11.47 11.98 12.54 13.18]"""
#%% vitesse

rw_vitesse="""[0.03616327 0.03370246 0.03273953 0.03241855 0.0317766 0.03124164 0.03070668 0.02995774 0.02920879 0.02867384 0.02813888 0.02738993
0.02685497 0.02610603 0.02535709 0.02471513 0.02407318 0.02353822
0.02268229 0.02193334 0.02129139 0.02054245 0.01957952 0.01883058
0.01808163 0.01733269 0.01647676 0.01572781 0.01465789 0.01358797 0.01241106 0.01123415 0.00995025]"""
#%% traitement

def traitement(données):
x=[]
elem=""
for a in données:
#les données étant des chaînes de caractères et n'étant pas des listes, on doit de nouveau les traiter pour utilisation ultérieure if a==" " or a=="[" or a=="]" or a=="\n":

if elem !="":
x.append(elem)
elem=""

else:
elem=elem+a

for i in range(len(x)):

x[i]=float(x[i])

return x

temps=np.array(traitement(rw_temps))

vitesse=np.array(traitement(rw_vitesse))
#définition d'une fonction de reference pour l'utilisation de curve_fit

def fonctionRef(t,A,B,tau):
return A*np.exp(-t/tau)+B
#Cette ligne renvoie une liste des paramètres dans l'ordre de la définition de la fonction de reference

paramètres, covariance = curve_fit(fonctionRef, temps-temps[0], vitesse) temps=temps-temps[0]
#Tracés des différentes courbes plt.plot(temps,vitesse,marker='+',color="red",linestyle= "None", label="Points expérimentaux")

plt.plot(temps, fonctionRef(temps,*paramètres),color="black", label="Prévisions théoriques")

plt.xlabel("temps en s")
plt.ylabel("vitesse angulaire en rad/s")
plt.title("Vitesse Angulaire du volant en rad/s en fonction du temps") plt.legend()
plt.grid()
plt.show()

plt.plot(temps, 1/2*J*(vitesse)**2, color="green", label="Énergie mécanique") plt.xlabel("temps en s")
plt.ylabel("Énergie mécanique en Joules")
plt.title("Énergie mécanique du volant en Joules en fonction du temps") plt.legend()
plt.show()
print(paramètres)

### 3) Expérience 2:

import numpy as np
import matplotlib.pyplot as plt from scipy.optimize import curve_fit

J=6.6e-2 #kg.m-3

#%% temps

rw_temps="""[24.27 24.41 24.55 24.7 24.84 24.99 25.14 25.28 25.43 25.58 25.73 25.88
26.03 26.18 26.33 26.48 26.64 26.79 26.95 27.11 27.27 27.44 27.61 27.81
28. 28.2 28.4 28.61 28.82 29.04 29.26 29.48 29.71 29.94 30.18 30.43 30.68 30.94 31.21 31.48 31.76 32.05 32.35 32.66 32.99 33.32 33.68 34.04
34.43 34.84 35.27 35.74 36.25 36.81 37.45]"""
rw_temps1="""[32.47 32.67 32.87 33.07 33.28 33.49 33.72 33.94 34.18 34.42 34.67 34.93
35.19 35.47 35.75 36.04 36.35 36.67 37.02 37.38 37.77 38.15 38.59 39.03
39.49 40.01 40.59]"""
#%% vitesse

rw_vitesse="""[0.04579254 0.04557856 0.04525758 0.04536457 0.04472262 0.04450864 0.04461563 0.04429466 0.04397368 0.04408067 0.0437597 0.04311774
0.04290376 0.04290376 0.04301075 0.04268978 0.0423688 0.04204783
0.04140587 0.04097791 0.03990799 0.03905205 0.03616327 0.03370246
0.03273953 0.03241855 0.0317766 0.03124164 0.03070668 0.02995774 0.02920879 0.02867384 0.02813888 0.02738993 0.02685497 0.02610603 0.02535709 0.02471513 0.02407318 0.02353822 0.02268229 0.02193334 0.02129139 0.02054245 0.01957952 0.01883058 0.01808163 0.01733269 0.01647676 0.01572781 0.01465789 0.01358797 0.01241106 0.01123415 0.00995025]"""
rw_vitesse1="""[0.02685497 0.02674798 0.02589205 0.02503611 0.02482213 0.02418017

0.02321725 0.02268229 0.02182635 0.02107741 0.02043546 0.02011448 0.01936554 0.01883058 0.01829562 0.01754668 0.01669074 0.0159418 0.01476489 0.01401594 0.01316001 0.013267 0.01176911 0.01155513 0.01102017 0.00984326 0.00866635]"""
#%% traitement

temps=np.array(traitement(rw_temps)) vitesse=np.array(traitement(rw_vitesse)) temps1=np.array(traitement(rw_temps1)) vitesse1=np.array(traitement(rw_vitesse1))
#Tableau de la dérivé de la vitesse

dérivé=np.diff(vitesse,axis=0)
#Obtention du minimum de la dérivé qui correspond au point de couplage minidér=min(dérivé)

# cette fonction renvoi l'indice du minimum

def reference(liste):
for i in range(len(liste)):
if liste[i]==minidér:
return i
#La vitesse de la roue est modélisé à l'aide de curve_fit

def vitesseR(t):
return (3.28852977e-02)*np.exp(-t/ 1.00160173e+01)-5.73919104e-03

temps=temps-temps[0]
#Tracé de l'efficacité au cours du temps, on sépare tout d'abord l'intervalle de temps en 2, car la roue n'est pas initialement en mouvement temps_1=temps[:reference(dérivé)+1]

temps_2=temps[reference(dérivé)+1:]
vitesse_1=vitesse[:reference(dérivé)+1] vitesse_2=vitesse[reference(dérivé)+1:]
#L'efficacité est nulle avant le début du roulage fonction_nulle=np.array([0 for i in range(len(temps_1))]) #Traçé de la dérivé

plt.xlabel("temps en s")
plt.ylabel("vitesse angulaire en rad/s")
plt.title("Vitesse Angulaire du volant en rad/s en fonction du temps") plt.plot(temps,vitesse,marker="+",linestyle="None" ,color="green", label="Points éxpérimentaux")
plt.plot(np.delete(temps,0, axis=0)-temps[0], dérivé,marker="+",linestyle="None", color="red", label="Dérivé")
plt.legend()
plt.show()
# Traçé de l'efficacité du système plt.plot(temps_1,fonction_nulle/(1/2)*J*(vitesse_1)**2,color="green") plt.plot(temps_2, ((J1*vitesseR(temps_2))**2)/(J*vitesse_2)**2, color="green") plt.title("Rendement énergétique du sytème en fonction du temps") plt.xlabel("temps en s")

plt.ylabel("Rendement global")
plt.legend()
plt.grid()
plt.show()

Gyan Louisin n°39070

# TIPE: Recueil des programmes utilisés

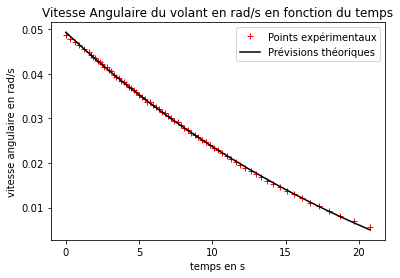
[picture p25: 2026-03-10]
tipe-courbes/volant 4.png

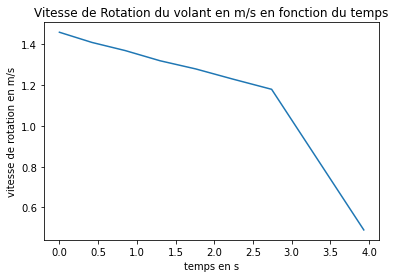
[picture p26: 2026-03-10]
bin_curves/Figure 2024-02-07 210749 (7).png

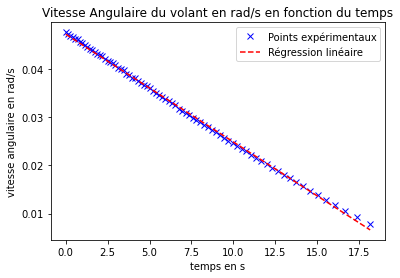
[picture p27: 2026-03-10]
tipe-courbes/VOLANT 1 (2).png

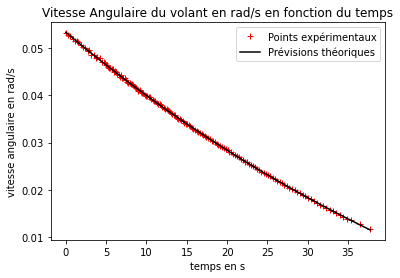
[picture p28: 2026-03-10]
tipe-courbes/volant 2.png

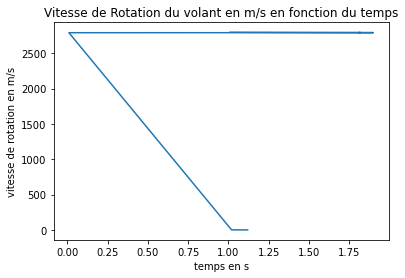
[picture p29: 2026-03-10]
bin_curves/Figure 2024-02-07 210749 (1).png

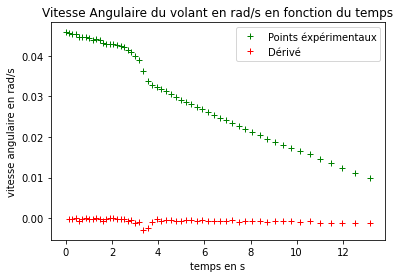
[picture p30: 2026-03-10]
tipe-courbes/exopdrusrtdgvj;gy.png

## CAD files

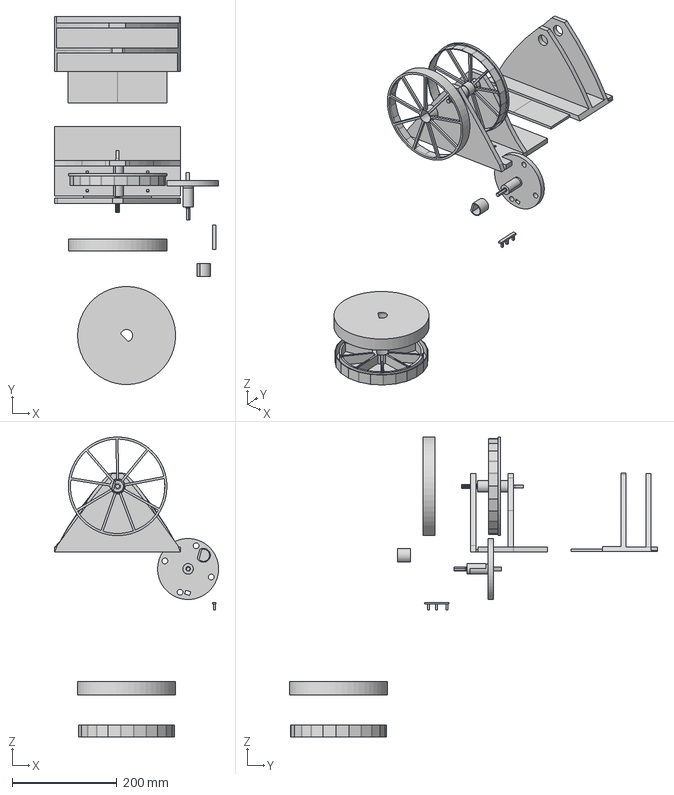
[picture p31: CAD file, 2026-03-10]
3D_model/TIPE_3D_model.step
313.1 x 701.8 x 572.1 mm
Partie A (glissière)
Partie B (butoire)
Fixation
BLOC 2
Axe bloc 1
608ZZ Shield x 2
608ZZ Ball x 7
608ZZ Outer ring
608ZZ Inner ring
Disque femelle
Axe Roue
support bobine
VOLANT 1
partie 2
Partie A
Partie B
Volant 2_1

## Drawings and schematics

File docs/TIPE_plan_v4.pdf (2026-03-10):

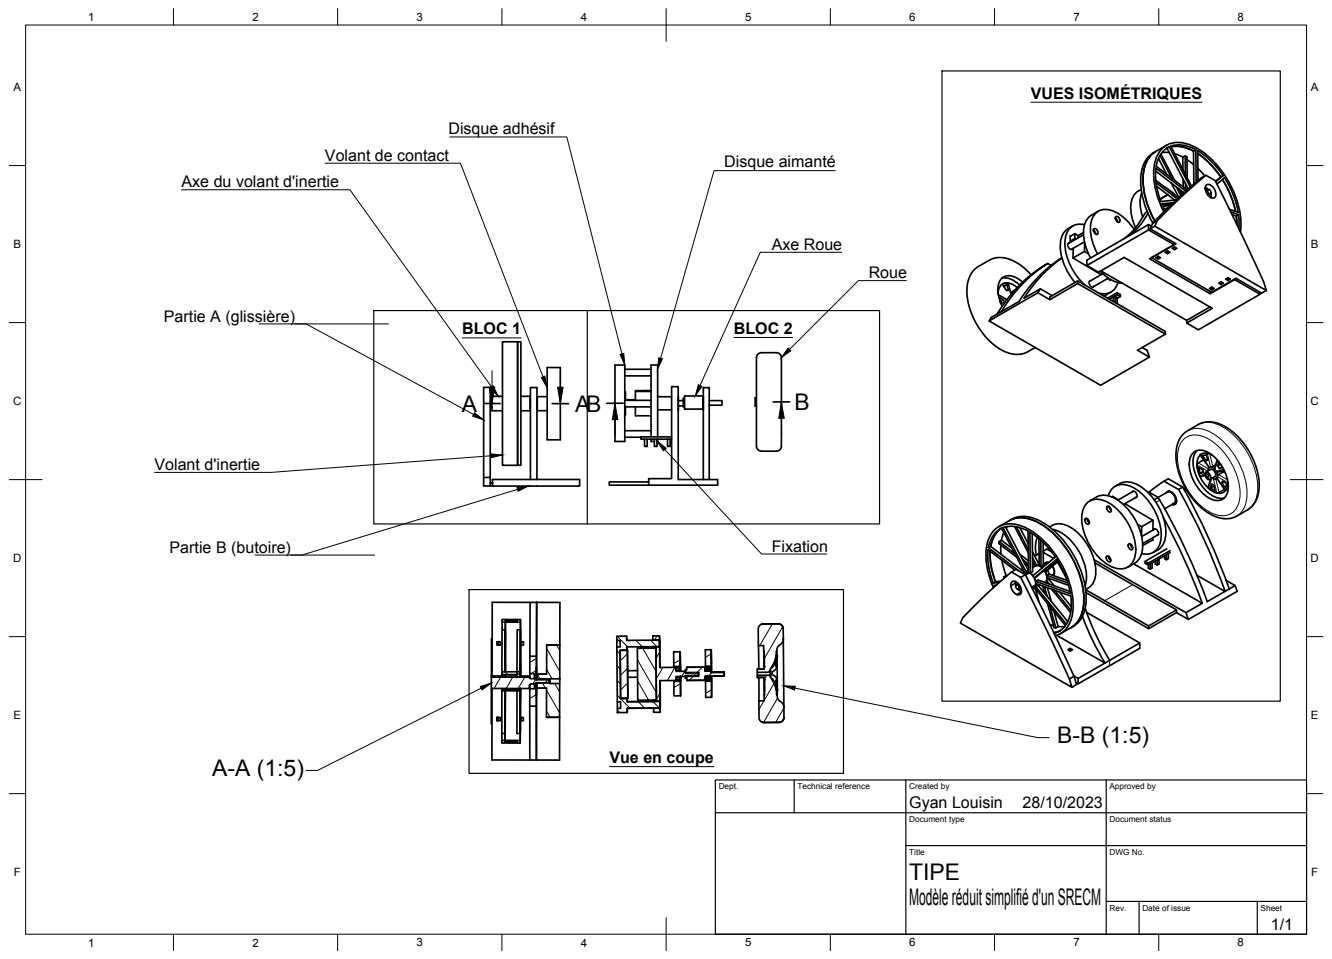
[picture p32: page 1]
Title; DWG No.; Rev.; Date of issue; Sheet; Axe Roue; Partie A (glissière); Partie B (butoire); Disque adhésif; Disque aimanté; Volant d'inertie; BLOC 1; BLOC 2; VUES ISOMÉTRIQUES

Volant de contact

Axe du volant d'inertie

Vue en coupe

Dept. | Technical reference | Created by Gyan Louisin 28/10/2023 | Approved by

Document type | Document status

TIPE
Modèle réduit simplifié d'un SRECM

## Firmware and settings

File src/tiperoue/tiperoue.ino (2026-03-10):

/*
Created on Wed Feb  7 15:31:12 2024

@author: gyanlouisin

TIPE project: Arduino sketch for measuring flywheel rotation speed.

This sketch reads two sensor coils (or hall-effect sensors) to detect the
passage of a magnet and computes rotational speed in tours/second.
The value is printed over Serial and displayed on an LCD.

Skills demonstrated:
 - embedded system data acquisition with interrupts
 - basic signal debouncing and timing with micros()
 - serial communication with Python scripts for logging/plotting

How to adapt for your setup:
 - Update `pinBobineVitesse` and `pinBobineDetection` to match your wiring.
 - Adjust the scaling factor in the speed calculation if your flywheel geometry
   changes (currently uses a fixed circumference factor 74.96).
 - Ensure the Arduino is connected to the host and the correct serial port is
   used in the Python scripts.
*/

#include <LiquidCrystal.h>
//definition de pi
#define PI 3.1415926535897932384626433832795
//initialisation des ports 
const int pinBobineVitesse=A0;
const int pinBobineDetection=A1;
//paramétrage de l'écran
LiquidCrystal lcd(7, 8, 9, 10, 11, 12);
// definition des variables de debut et de fin de tour
volatile unsigned long debut =0;
volatile unsigned long fin=0;
//defintion d'une variable drapeau
volatile bool flag=false;
void setup() { 
  // inilitialisation de l'écran
  lcd.begin(16, 2);
  lcd.print("V. de Rotation:");
  //Ports de bobine en INPUT
  pinMode(pinBobineVitesse,INPUT);
  pinMode(pinBobineDetection,INPUT);
  //defintion d'un port quelconque qui servira de condition de sortie de la boucle 
  pinMode(2,OUTPUT);
  Serial.begin(9600);
  //definition d'une interruption logique (on active la fonction detectionAimant): on interrompt la boucle si le port 2 passe d'un niveau LOW à HIGH 
  attachInterrupt(digitalPinToInterrupt(2),detectionAimant,RISING); 
  Serial.println("Ready"); 
  }

void loop() {
  // si une tension est detectée par la première bobine, on sort de la boucle pour entrer dans la fonction detection aimant (passage de LOW à HIGH)
  if (analogRead(pinBobineVitesse) != 0){
    digitalWrite(2,HIGH);
  }
//si le drapeau est levé, on considère que l'aimant a fait un tour (il est dejà passé une fois)
 if (flag==true){  
  fin=micros();
  //calcul de la vitesse à l'aide des variables mises à jour
  float vitesse=(2*PI*74.96)/((fin-debut)*pow(10,-3));
  // impression des données dans le buffer
  Serial.print(vitesse);Serial.print(" tours/s ; ");Serial.print(fin*pow(10,-6));Serial.println(" secondes");
  // mise à jour de l'écran
  lcd.setCursor(2, 1);
  lcd.print(vitesse);
  lcd.setCursor(7, 1);
  lcd.print("tours/s");
  // on baisse le drapeau et on réinitialise les variables à la fin du tour
  flag=false;
  fin=0;
  debut=0;

     
  }
  
 }
 
void detectionAimant(){
  // si l'aimant n'est pas déjà passé devant la bobine avant detection, on demarre le compteur 
  if (debut == 0){
    debut=micros();
    //tant que l'aimant ne passe pas devant la 2nde bobine, on attend afin d'éviter les erreurs de mesures 
     while (analogRead(pinBobineDetection)==0){
      delayMicroseconds(1);
      }
      //le drapeau reste baissé car l'aimant commence son tour
    flag=false;
  }
  // si l'aimant passe pour la 2nde fois, on lève le drapeau, ce qui permet de continuer la boucle principale
  else{

    flag=true;
  }
  digitalWrite(2,LOW);
}

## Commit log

2026-03-10 Import du Projet
    [TIPE_Volant1_raws.csv, TIPE_Volant2_raws.csv, TIPE_Volant3_raws.csv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]
2026-03-10 Readme update
    [TIPE_3D_model.step]
